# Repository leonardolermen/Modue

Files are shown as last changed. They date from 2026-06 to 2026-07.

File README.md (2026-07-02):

# Modue — Mixer Modular Magnético

Controlador físico modular para PC que controla individualmente o volume de aplicações (Discord, Spotify, Chrome, jogos…) através de módulos magnéticos, cada um com display touch e fader motorizado, comunicando via Bluetooth Low Energy.

> Inspirado em produtos como Monogram Creative Console e Intech Studio Grid, porém open-source, modular e a uma fração do custo.

## Arquitetura

Arquitetura do Modue

O firmware é um renderizador genérico **controlado pelo app de PC**: o módulo recebe comandos (volume, estado, cor, imagens) e devolve eventos de toque. Detalhes em [`docs/architecture.md`](docs/architecture.md) e o contrato em [`PROTOCOL.md`](PROTOCOL.md).

> 🛠️ **Rodar do zero numa máquina nova:** ver [`SETUP.md`](SETUP.md) (Arduino/libs, app Node, OpenSCAD, git).

## Hardware

- **MCU + Display:** ESP32-C6-Touch-LCD-1.47 (SpotPear/Waveshare) — display **JD9853** 172×320 + touch **AXS5106L**
- **Fader motorizado:** ALPS RS60N11M9A0
- **Driver de motor:** DRV8833 / TB6612FNG
- **Conexão entre módulos:** pogo pins magnéticos (energia) + BLE (dados)

## Pinagem (placa Touch — JD9853)

| Display | GPIO | | Touch | GPIO |
|---|---|---|---|---|
| SCK | 1 | | SDA | 18 |
| MOSI | 2 | | SCL | 19 |
| DC | 15 | | RST | 20 |
| CS | 14 | | INT | 21 |
| RST | 22 | | | |
| BL | 23 | | | |

**Fader físico** (potenciômetro 10kΩ, Donghong 119C 10KB — wiper no ADC1):

| Pino do fader | Liga em |
|---|---|
| 1 | 3.3V |
| 3 (wiper) | GPIO3 |
| 4 | GND |
| 2 | não usado |

> Motor (ponte-H) ainda não ligado. A leitura tem auto-calibração: deslize o curso completo uma vez após ligar.

> ⚠️ É a variante **Touch** (JD9853, não ST7789). O JD9853 precisa de sequência de init própria — ver `modue/`.

## Firmware (Arduino IDE)

| Sketch | Descrição |
|---|---|
| `modue/` | **Firmware principal** — renderizador dinâmico controlado pelo PC (LVGL) |
| `discordUI/` | UI do módulo em LVGL com tela Discord fixa (histórico) |
| `displayHello/` | Teste do display JD9853 + fader touch (Arduino_GFX) |

**Libs:** GFX Library for Arduino, LVGL 8.4, esp_lcd_touch_axs5106l
**Board:** ESP32C6 Dev Module · USB CDC On Boot: Enabled

## App de PC

Em `app/` (Node/Electron). Lê os eventos do módulo e aplica nos serviços (Discord, Spotify, volume). Veja [`app/README.md`](app/README.md) e o [`PROTOCOL.md`](PROTOCOL.md).

## Roadmap

- [x] Display JD9853 + touch AXS5106L
- [x] UI em LVGL (logo, fader, botões mute)
- [x] Ícones/logo reais no display
- [x] Protocolo bidirecional + firmware dinâmico (Fase A)
- [x] Envio de imagem pro display (Fase B)
- [x] Spotify — play/pause/skip + capa do álbum + volume (Web API)
- [x] Fader físico (potenciômetro via ADC, auto-calibrado)
- [ ] Shell do app Electron (Fase C)
- [ ] Discord RPC nativo + estado de volta (Fase D)
- [ ] Multi-módulo + perfis (Fase F)
- [ ] Fader motorizado (ponte-H) + BLE

Documentação completa em [`claude.md`](claude.md).

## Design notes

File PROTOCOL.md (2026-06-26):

# Protocolo Modue (PC ↔ módulo)

Comunicação por **USB serial** a **115200 baud**, linhas terminadas em `\n` (ASCII).
Bidirecional: o PC manda comandos, o módulo manda eventos.

## PC → Módulo (comandos)

| Comando | Efeito |
|---|---|
| `PING` | Módulo responde `PONG` (handshake/keepalive) |
| `SCREEN <discord\|spotify>` | Troca a tela/layout do módulo |
| `VOL <0-100>` | Move o fader pra essa posição (sem gerar evento de volta) |
| `STATE <mic\|deaf\|play> <0\|1>` | Define o estado de um botão (1 = ativo/mutado/tocando) |
| `LABEL <texto>` | Texto principal (nome da faixa na tela Spotify) |
| `COLOR <RRGGBB>` | Cor de destaque (fader e realces) |
| `IMG <slot> <w> <h>`<br>+ `w*h*2` bytes RGB565 | Envia imagem pro display (ex.: `IMG art 140 140` + bytes). Slot `art` = capa do álbum. RGB565 little-endian, opaco. |

## Módulo → PC (eventos)

| Evento | Quando |
|---|---|
| `HELLO modue <versao>` | No boot |
| `PONG` | Resposta ao `PING` |
| `EV VOL <0-100>` | Usuário moveu o fader |
| `EV BTN <mic\|deaf> <0\|1>` | Tela Discord: tocou no botão (estado novo) |
| `EV BTN play <0\|1>` | Tela Spotify: play/pause (1 = tocando) |
| `EV BTN <prev\|next> 1` | Tela Spotify: faixa anterior / próxima (momentâneo) |

## Regras

- Comandos/eventos desconhecidos são ignorados (compatibilidade pra frente).
- O PC é a fonte da verdade do estado: ao receber `EV BTN`, aplica no serviço
  (Discord etc.) e devolve `STATE` confirmando — assim o módulo reflete o estado real.
- `VOL`/`STATE` vindos do PC **não** geram `EV` de volta (evita eco/loop).

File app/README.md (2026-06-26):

# Modue PC bridge

Ponte entre o módulo físico e o PC: lê os eventos do fader/botões pela porta serial e aplica no Discord.

```
modulo (ESP32) --USB serial--> este app --> Discord (mute / deafen / volume)
```

Eventos que o firmware envia: `VOL <0-100>`, `MUTE_MIC on|off`, `MUTE_FONE on|off`.

## Instalar

```bash
cd pc
npm install
```

## Configurar o Discord (atalhos globais)

O app simula os **atalhos globais** do Discord. Configure em
**Discord → Configurações → Atalhos de Teclado** e adicione:

| Ação | Atalho (macOS) | Atalho (Windows) |
|---|---|---|
| Alternar mudo (mute) | `Ctrl+Alt+Cmd+M` | `Ctrl+Alt+Win+M` |
| Alternar surdo (deafen) | `Ctrl+Alt+Cmd+D` | `Ctrl+Alt+Win+D` |

> Os atalhos precisam bater com o `config.json` (`keybinds`). Pode trocar à vontade,
> só mantenha os dois lados iguais.

## Rodar

```bash
npm start
```

A porta serial é **auto-detectada** (`usbmodem` no Mac, `COM` no Windows). Para fixar,
edite `serialPort` no `config.json`.

> ⚠️ Feche o **Serial Monitor do Arduino** antes — a porta não pode ser aberta por dois programas.

## Notas por sistema

### macOS
- **Permissão necessária:** ao enviar o primeiro atalho, o macOS pede acesso de
  **Acessibilidade**. Vá em *Ajustes → Privacidade e Segurança → Acessibilidade* e
  habilite o **Terminal** (ou o app que rodou o `npm start`).
- **Volume:** o macOS não tem volume por-app nativo, então o fader controla o
  **volume de saída do sistema**. (Por-app exigiria um driver de áudio virtual.)

### Windows
- **Volume por-app:** usa o `svcl.exe` (NirSoft *SoundVolumeView*). Baixe em
  https://www.nirsoft.net/utils/sound_volume_view.html e coloque o `svcl.exe` na
  pasta `pc/` (ou ajuste `windows.svclPath` no `config.json`).
- O nome do processo do Discord está em `discordProcess` (`Discord.exe`).

## config.json

| Campo | Descrição |
|---|---|
| `serialPort` | `"auto"` ou caminho fixo (`/dev/cu.usbmodem1101`, `COM5`) |
| `baud` | 115200 (igual ao firmware) |
| `discordProcess` | nome do processo p/ volume no Windows |
| `keybinds.mute` / `.deafen` | combinação de teclas (precisa bater com o Discord) |
| `windows.svclPath` | caminho do `svcl.exe` |

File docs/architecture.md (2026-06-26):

# Arquitetura

Arquitetura do Modue

O firmware é um **renderizador genérico controlado pelo PC**. Em vez de telas fixas,
o módulo recebe comandos (volume, estado dos botões, cor, imagens) e devolve eventos
(toques no fader e nos botões). Quem decide o que cada módulo representa — Discord,
Spotify, etc. — é o app de PC.

## Camadas

- **Hardware (módulos):** ESP32-C6 + display touch JD9853. Cada módulo é um app.
  Desenha a UI em LVGL e emite eventos de toque.
- **App de PC (Electron):** núcleo do sistema.
  - *Gerenciador:* detecta módulos, guarda perfis e qual app está em cada um.
  - *Protocolo + imagens:* fala o [protocolo serial](../PROTOCOL.md) e envia logos/capas.
  - *Integrações:* conecta nos serviços e mantém o estado em tempo real.
- **Serviços externos:** Discord (RPC), Spotify (API) e o volume do sistema operacional.

## Comunicação

PC e módulo conversam por **USB serial, bidirecional** (futuramente BLE). O contrato
completo de comandos e eventos está em [`PROTOCOL.md`](../PROTOCOL.md).

## Fases de implementação

| Fase | Entrega | Status |
|---|---|---|
| A | Protocolo bidirecional + firmware dinâmico | ✅ |
| B | Envio de imagem pro display | ⏳ |
| C | Shell do app (Electron) | ⏳ |
| D | Discord RPC nativo (+ estado de volta) | ⏳ |
| E | Spotify (play/skip + capa) | ⏳ |
| F | Multi-módulo + perfis | ⏳ |

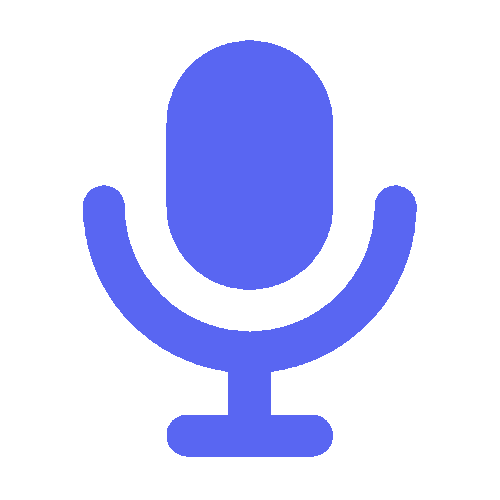
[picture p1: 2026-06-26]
assets/mic.png

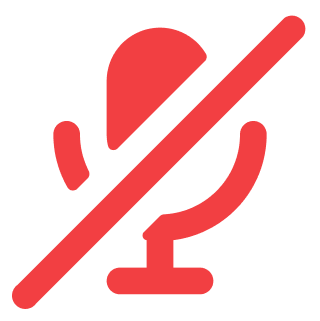
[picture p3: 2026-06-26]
assets/mic_muted.png

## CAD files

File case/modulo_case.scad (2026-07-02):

// ============================================================
//  Modue — Case do módulo (bandeja/corpo)  v1
//  Fader vertical + display no topo (em linha). Unidades: mm.
//
//  Origem: centro em X e Y; Z=0 = traseira (aberta, recebe a tampa);
//  frente (com janela do display + fenda do knob) em Z = out_d.
//  Componentes entram pela traseira.
// ============================================================

// ---------- Impressão / tolerâncias ----------
wall = 2.0;    // espessura de parede
fit  = 0.3;    // folga de encaixe (FDM)
$fn  = 40;

// ---------- Placa ESP32-C6-LCD-1.47 ----------
pcb_l = 36.37;
pcb_w = 20.32;
win_w = 17.7;   // janela do display (área visível)
win_h = 32.9;

// ---------- Fader (ALPS 80mm, travel 60) ----------
fad_l    = 80.0;
fad_w    = 18.0;
fad_up   = 8.2;    // acima da superfície de montagem
fad_deep = 17.8;   // abaixo (26 total − 8.2)
fad_trav = 60.0;   // curso do knob
slot_w   = 4.0;    // largura da fenda do knob

// ---------- Arranjo ----------
gap_fd = 4.0;   // vão fader <-> placa
usb_w  = 9.5;   // rasgo USB-C (largura)
usb_h  = 3.6;   // rasgo USB-C (altura)

// ---------- Derivadas ----------
inner_w = max(fad_w, pcb_w) + 2*fit;
inner_l = fad_l + gap_fd + pcb_l + 2*fit;
inner_d = fad_deep + fad_up + fit;    // profundidade útil (fader é o mais fundo)

out_w = inner_w + 2*wall;
out_l = inner_l + 2*wall;
out_d = inner_d + wall;               // parede da frente

// centros no comprimento (Y)
fad_y  = -inner_l/2 + fit + fad_l/2;
disp_y =  inner_l/2 - fit - pcb_l/2;

module box(w, l, d) { translate([-w/2,-l/2,0]) cube([w,l,d]); }

module tray() {
  difference() {
    // casca sólida
    box(out_w, out_l, out_d);

    // cavidade interna aberta na traseira (Z de -1 até out_d-wall)
    translate([0,0,-1]) box(inner_w, inner_l, (out_d - wall) + 1);

    // fenda do knob na frente (sobre o fader)
    translate([0, fad_y, out_d - wall - 1])
      box(slot_w, fad_trav, wall + 2);

    // janela do display na frente
    translate([0, disp_y, out_d - wall - 1])
      box(win_w, win_h, wall + 2);

    // rasgo do USB-C (parede lateral, perto da base/placa)
    translate([out_w/2 - wall - 1, disp_y, wall])
      box(wall + 2, usb_w, usb_h);
  }
}

tray();

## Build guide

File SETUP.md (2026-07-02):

# Setup do ambiente (máquina nova)

Guia pra colocar o projeto pra rodar do zero. Três frentes: **firmware** (Arduino),
**app de PC** (Node) e **case** (OpenSCAD).

---

## 1. Firmware (Arduino IDE)

### Board
- Instale o core **esp32** (Espressif) pelo Boards Manager — versão **≥ 3.0** (testado na 3.3.10).
- Selecione **ESP32C6 Dev Module**.
- Em *Tools*: **USB CDC On Boot: Enabled**, Flash Size **8MB**.

### Bibliotecas
| Lib | Como instalar | Versão |
|---|---|---|
| **GFX Library for Arduino** (moononournation) | Library Manager | 1.6.x |
| **LVGL** | ⚠️ **fixar na 8.4.0** — **NÃO** usar 9.x (API incompatível, quebra tudo) | 8.4.0 |
| **esp_lcd_touch_axs5106l** | copiar do demo da Waveshare (não está no Library Manager) | — |

O jeito mais garantido de ter a LVGL 8.4 + o driver de touch é pegar do **demo oficial**:

```
https://files.waveshare.com/wiki/ESP32-C6-Touch-LCD-1.47/ESP32-C6-Touch-LCD-1.47-Demo.zip
```

Dentro dele, copie `Arduino/libraries/lvgl` e `Arduino/libraries/esp_lcd_touch_axs5106l`
para a pasta de bibliotecas do Arduino (`~/Documents/Arduino/libraries/` no Mac,
`Documentos\Arduino\libraries\` no Windows).

> Se o Library Manager sugerir atualizar a LVGL pra 9.x, **ignore** — quebra a compilação.

### lv_conf.h (crítico)
Copie o `lv_conf.h` do exemplo do demo (`Arduino/examples/04_lvgl_arduino_v8/lv_conf.h`)
para a **raiz** da pasta de bibliotecas (`libraries/lv_conf.h`), e ajuste:

- `LV_COLOR_16_SWAP` → **0**  (senão as cores saem trocadas)
- `LV_TICK_CUSTOM` → **1**  (usa `millis()` do Arduino)
- Habilite as fontes: `LV_FONT_MONTSERRAT_20`, `_28`, `_40` → **1**

### Pinagem (já no código, mas pra referência)
Placa **ESP32-C6-Touch-LCD-1.47** (JD9853 + AXS5106L):
- Display (HW SPI): SCK=1, MOSI=2, DC=15, CS=14, RST=22, BL=23
- Touch (I²C): SDA=18, SCL=19, RST=20, INT=21
- Fader (pot 10k): wiper→GPIO3, extremos no 3V3/GND

Abra `modue/modue.ino` (as abas `board/screens/protocol/fader` aparecem sozinhas) e grave.

---

## 2. App de PC (Node)

```bash
cd app
npm install
```

- **Spotify:** o `config.json` já tem o `clientId` (público, ok no git). Registre o
  Redirect URI `http://127.0.0.1:8888/callback` no [Spotify Dashboard](https://developer.spotify.com/dashboard)
  se ainda não estiver. Os tokens (`.spotify-tokens.json`) **não** vão pro git — na
  primeira execução ele abre o navegador pra você autorizar de novo.
- Rodar o Spotify: `node src/spotify-run.js`
- **Windows:** pro volume por-app do Discord, baixe o `svcl.exe` (NirSoft) — ver `app/README.md`.

---

## 3. Case (OpenSCAD)

- Instale o **OpenSCAD** (https://openscad.org ou `brew install --cask openscad`).
- Abra `case/modulo_case.scad`. Variáveis de medida no topo do arquivo.

---

## 4. Git (empurrar de uma máquina nova)

Clone com a URL padrão (usa a chave SSH da conta pessoal da própria máquina):

```bash
git clone git@github.com:leonardolermen/Modue.git
```

> Obs: no Mac de trabalho foi usado um alias `github-personal` no `~/.ssh/config`
> porque a chave padrão dali era da conta do trabalho. Numa máquina pessoal onde a
> conta do GitHub já é a `leonardolermen`, não precisa de alias — a URL padrão funciona.
> (Ou use HTTPS + token.)

---

## Estrutura do repo

| Pasta | O que é |
|---|---|
| `modue/` | firmware (abas .ino) — firmware principal |
| `app/` | app de PC (Node): serial + Spotify + imagens |
| `case/` | modelo 3D do case (OpenSCAD) |
| `docs/` | arquitetura + diagrama |
| `discordUI/`, `displayHello/` | sketches antigos (histórico) |
| `PROTOCOL.md` | contrato serial PC↔módulo |

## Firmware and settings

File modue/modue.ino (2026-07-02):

// ============================================================
//  Mixer Modular Magnético — Firmware dinâmico (controlado pelo PC)
//  Placa: SpotPear/Waveshare ESP32-C6-Touch-LCD-1.47 (JD9853 + AXS5106L)
//
//  Renderizador genérico com telas trocáveis (Discord / Spotify).
//  PC manda comandos (SCREEN/VOL/STATE/COLOR/LABEL/IMG); módulo devolve
//  eventos (EV VOL / EV BTN). Ver PROTOCOL.md.
//
//  Organização (abas .ino, concatenadas pelo Arduino):
//    modue.ino    -> includes, config, globais, setup(), loop()
//    board.ino    -> init JD9853 + glue do LVGL/touch
//    screens.ino  -> telas Discord/Spotify + callbacks de toque
//    protocol.ino -> serial: comandos do PC e recepção de imagem
//    fader.ino    -> leitura do fader físico (ADC) + calibração
//
//  Libs: GFX Library for Arduino, lvgl 8.4, esp_lcd_touch_axs5106l
//  Board: ESP32C6 Dev Module | USB CDC On Boot: Enabled
// ============================================================

#include <lvgl.h>
#include <Arduino_GFX_Library.h>
#include <Wire.h>
#include "esp_lcd_touch_axs5106l.h"
#include "icons.h"  // img_discord, img_mic, img_mic_muted (defaults)

#define FW_VERSION "0.3.0"

// ---- Display JD9853 ----
#define GFX_BL 23
Arduino_DataBus *bus = new Arduino_HWSPI(15, 14, 1, 2);
Arduino_GFX *gfx = new Arduino_ST7789(bus, 22, 0, false, 172, 320, 34, 0, 34, 0);

// ---- Touch AXS5106L ----
#define TP_SDA 18
#define TP_SCL 19
#define TP_RST 20
#define TP_INT 21

// ---- Fader fisico (potenciometro do ALPS, via ADC) ----
#define FADER_ENABLED 1   // 0 = desliga (use 0 enquanto NAO ligou o fader no GPIO3)
#define FADER_DEBUG   0   // 1 = imprime o valor cru do ADC no serial (debug)
#define FADER_PIN 3       // wiper do potenciometro -> ADC1_CH3

// ---- Cores ----
#define C_BG       0x0a0b10
#define C_TRACK    0x1c1f29
#define C_BTN      0x15171f
#define C_BTN_MUTE 0x2b1417
#define C_RED      0xe24b4a
#define C_LIGHT    0xcfd2da

// ---- Capa do album (recebida via comando IMG) ----
#define MAX_ART 40000  // 140*140*2 = 39200

// Tipos no topo (o Arduino gera protótipos antes das funções nas outras abas)
enum Screen { SCR_DISCORD, SCR_SPOTIFY };

// ============================================================
//  Globais (definidos aqui; visíveis em todas as abas .ino — é uma TU só)
//  static = linkagem interna, evita colisão de nome com as libs.
// ============================================================
static uint32_t accent = 0x5865F2;

// LVGL glue
static lv_disp_draw_buf_t draw_buf;
static lv_color_t *buf1;
static lv_disp_drv_t disp_drv;

// Estado
static Screen current = SCR_DISCORD;
static bool suppressEv = false;

// Widgets
static lv_obj_t *slider, *volLabel;                                   // comuns
static lv_obj_t *micBtn, *micImg, *foneBtn, *foneLbl;                 // discord
static lv_obj_t *trackLabel, *prevBtn, *playBtn, *playLbl, *nextBtn, *artImg;  // spotify

// Recepcao de imagem (nao-bloqueante)
static uint8_t *artBuf = NULL;
static lv_img_dsc_t artDsc;
static int imgW = 0, imgH = 0;
static size_t imgRemaining = 0, imgPos = 0;
static uint32_t imgLast = 0;

// Parser de comandos
static char lineBuf[160];
static uint8_t lineLen = 0;

// ============================================================
void setup() {
  Serial.setRxBufferSize(MAX_ART + 2048);  // segura o jorro da imagem sem perder bytes
  Serial.begin(115200);
  delay(300);

#if FADER_ENABLED
  // ADC: por padrao o ESP32 satura em ~1.1V. Com 12dB le o range ~0..3.3V.
  analogReadResolution(12);
  analogSetPinAttenuation(FADER_PIN, ADC_11db);
#endif

  if (!gfx->begin()) Serial.println("gfx->begin() FALHOU");
  lcd_reg_init();
  gfx->setRotation(0);
  gfx->fillScreen(RGB565_BLACK);
  pinMode(GFX_BL, OUTPUT);
  digitalWrite(GFX_BL, HIGH);

  Wire.begin(TP_SDA, TP_SCL);
  bsp_touch_init(&Wire, TP_RST, TP_INT, gfx->getRotation(), gfx->width(), gfx->height());

  lv_init();
  uint32_t bufSize = 172 * 40;
  buf1 = (lv_color_t *)heap_caps_malloc(bufSize * 2, MALLOC_CAP_INTERNAL | MALLOC_CAP_8BIT);
  if (!buf1) buf1 = (lv_color_t *)malloc(bufSize * 2);
  lv_disp_draw_buf_init(&draw_buf, buf1, NULL, bufSize);

  lv_disp_drv_init(&disp_drv);
  disp_drv.hor_res = 172;
  disp_drv.ver_res = 320;
  disp_drv.flush_cb = my_disp_flush;
  disp_drv.draw_buf = &draw_buf;
  lv_disp_drv_register(&disp_drv);

  static lv_indev_drv_t indev_drv;
  lv_indev_drv_init(&indev_drv);
  indev_drv.type = LV_INDEV_TYPE_POINTER;
  indev_drv.read_cb = touchpad_read_cb;
  lv_indev_drv_register(&indev_drv);

  switch_screen(SCR_DISCORD);
  txln("HELLO modue " FW_VERSION);
}

void loop() {
  pollSerial();
  // Enquanto recebe a imagem, drena rapido (sem desenhar) pra nao perder bytes.
  if (imgRemaining > 0) return;
#if FADER_ENABLED
  readFader();
#endif
  lv_timer_handler();
  delay(5);
}

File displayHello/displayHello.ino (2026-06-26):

// ============================================================
//  Mixer Modular Magnético — Teste 04: Fader TOUCH
//  Placa: SpotPear/Waveshare ESP32-C6-Touch-LCD-1.47
//  Display JD9853 172x320  |  Touch AXS5106L (I2C addr 0x63)
//
//  Arraste o dedo pra cima/baixo na barra: o volume acompanha.
//  Pinos display: SCK=1 MOSI=2 DC=15 CS=14 RST=22 BL=23
//  Pinos touch  : SDA=18 SCL=19 RST=20 INT=21
//
//  Lib: "GFX Library for Arduino" (Moon On Our Nation)
//  Board: ESP32C6 Dev Module | USB CDC On Boot: Enabled
// ============================================================

#include <Arduino_GFX_Library.h>
#include <Wire.h>

#define GFX_BL 23

// ---- Touch AXS5106L ----
#define TP_SDA 18
#define TP_SCL 19
#define TP_RST 20
#define TP_INT 21
#define TP_ADDR 0x63
#define TP_DATA_REG 0x01

Arduino_DataBus *bus = new Arduino_HWSPI(15 /* DC */, 14 /* CS */, 1 /* SCK */, 2 /* MOSI */);
Arduino_GFX *gfx = new Arduino_ST7789(
    bus, 22 /* RST */, 0 /* rotation */, false /* IPS */,
    172, 320, 34, 0, 34, 0);

// Para paisagem: troque o rotation acima pra 1 ou 3 e ajuste o layout.

// ---- Init proprio do JD9853 (demo oficial Waveshare) ----
void lcd_reg_init(void) {
  static const uint8_t op[] = {
    BEGIN_WRITE, WRITE_COMMAND_8, 0x11, END_WRITE, DELAY, 120,
    BEGIN_WRITE,
    WRITE_C8_D16, 0xDF, 0x98, 0x53,
    WRITE_C8_D8, 0xB2, 0x23,
    WRITE_COMMAND_8, 0xB7, WRITE_BYTES, 4, 0x00, 0x47, 0x00, 0x6F,
    WRITE_COMMAND_8, 0xBB, WRITE_BYTES, 6, 0x1C, 0x1A, 0x55, 0x73, 0x63, 0xF0,
    WRITE_C8_D16, 0xC0, 0x44, 0xA4,
    WRITE_C8_D8, 0xC1, 0x16,
    WRITE_COMMAND_8, 0xC3, WRITE_BYTES, 8, 0x7D, 0x07, 0x14, 0x06, 0xCF, 0x71, 0x72, 0x77,
    WRITE_COMMAND_8, 0xC4, WRITE_BYTES, 12, 0x00, 0x00, 0xA0, 0x79, 0x0B, 0x0A, 0x16, 0x79, 0x0B, 0x0A, 0x16, 0x82,
    WRITE_COMMAND_8, 0xC8, WRITE_BYTES, 32,
      0x3F, 0x32, 0x29, 0x29, 0x27, 0x2B, 0x27, 0x28, 0x28, 0x26, 0x25, 0x17, 0x12, 0x0D, 0x04, 0x00,
      0x3F, 0x32, 0x29, 0x29, 0x27, 0x2B, 0x27, 0x28, 0x28, 0x26, 0x25, 0x17, 0x12, 0x0D, 0x04, 0x00,
    WRITE_COMMAND_8, 0xD0, WRITE_BYTES, 5, 0x04, 0x06, 0x6B, 0x0F, 0x00,
    WRITE_C8_D16, 0xD7, 0x00, 0x30,
    WRITE_C8_D8, 0xE6, 0x14,
    WRITE_C8_D8, 0xDE, 0x01,
    WRITE_COMMAND_8, 0xB7, WRITE_BYTES, 5, 0x03, 0x13, 0xEF, 0x35, 0x35,
    WRITE_COMMAND_8, 0xC1, WRITE_BYTES, 3, 0x14, 0x15, 0xC0,
    WRITE_C8_D16, 0xC2, 0x06, 0x3A,
    WRITE_C8_D16, 0xC4, 0x72, 0x12,
    WRITE_C8_D8, 0xBE, 0x00,
    WRITE_C8_D8, 0xDE, 0x02,
    WRITE_COMMAND_8, 0xE5, WRITE_BYTES, 3, 0x00, 0x02, 0x00,
    WRITE_COMMAND_8, 0xE5, WRITE_BYTES, 3, 0x01, 0x02, 0x00,
    WRITE_C8_D8, 0xDE, 0x00,
    WRITE_C8_D8, 0x35, 0x00,
    WRITE_C8_D8, 0x3A, 0x05,
    WRITE_COMMAND_8, 0x2A, WRITE_BYTES, 4, 0x00, 0x22, 0x00, 0xCD,
    WRITE_COMMAND_8, 0x2B, WRITE_BYTES, 4, 0x00, 0x00, 0x01, 0x3F,
    WRITE_C8_D8, 0xDE, 0x02,
    WRITE_COMMAND_8, 0xE5, WRITE_BYTES, 3, 0x00, 0x02, 0x00,
    WRITE_C8_D8, 0xDE, 0x00,
    WRITE_C8_D8, 0x36, 0x00,
    WRITE_COMMAND_8, 0x21,
    END_WRITE, DELAY, 10,
    BEGIN_WRITE, WRITE_COMMAND_8, 0x29, END_WRITE
  };
  bus->batchOperation(op, sizeof(op));
}

// ---- Leitura do touch (polling, sem interrupcao) ----
// Retorna true se ha dedo na tela; preenche tx,ty em coords de tela.
bool lerTouch(int &tx, int &ty) {
  uint8_t d[14];
  Wire.beginTransmission(TP_ADDR);
  Wire.write(TP_DATA_REG);
  if (Wire.endTransmission() != 0) return false;
  if (Wire.requestFrom(TP_ADDR, (uint8_t)14) != 14) return false;
  for (int i = 0; i < 14; i++) d[i] = Wire.read();

  uint8_t n = d[1];               // numero de toques
  if (n == 0) return false;

  uint16_t rawX = ((uint16_t)(d[2] & 0x0F) << 8) | d[3];
  uint16_t rawY = ((uint16_t)(d[4] & 0x0F) << 8) | d[5];
  // rotation 0: x espelhado, y direto
  tx = 171 - rawX;
  ty = rawY;
  return true;
}

void resetTouch() {
  pinMode(TP_RST, OUTPUT);
  digitalWrite(TP_RST, LOW);  delay(200);
  digitalWrite(TP_RST, HIGH); delay(300);
  pinMode(TP_INT, INPUT_PULLUP);
}

// ---- Layout do fader ----
const int TRK_X = 46, TRK_W = 80;     // trilha
const int TRK_Y = 70, TRK_H = 200;    // topo e altura
#define COR_BARRA  0x07E0   // verde
#define COR_TRILHA 0x2104   // cinza bem escuro
#define COR_KNOB   0xFFFF   // branco

int volume = 50;
int volAnterior = -1;

void desenhaFader(int v) {
  // trilha
  gfx->fillRoundRect(TRK_X, TRK_Y, TRK_W, TRK_H, 10, COR_TRILHA);
  // preenchimento de baixo pra cima
  int fill = (TRK_H * v) / 100;
  gfx->fillRoundRect(TRK_X, TRK_Y + (TRK_H - fill), TRK_W, fill, 10, COR_BARRA);
  // "knob" (linha do nivel)
  int ky = TRK_Y + (TRK_H - fill);
  gfx->fillRoundRect(TRK_X - 6, ky - 4, TRK_W + 12, 8, 4, COR_KNOB);

  // numero
  gfx->fillRect(0, TRK_Y + TRK_H + 14, 172, 40, RGB565_BLACK);
  gfx->setTextColor(RGB565_WHITE);
  gfx->setTextSize(4);
  char buf[8];
  snprintf(buf, sizeof(buf), "%d", v);
  int16_t x1, y1; uint16_t w, h;
  gfx->getTextBounds(buf, 0, 0, &x1, &y1, &w, &h);
  gfx->setCursor((172 - w) / 2, TRK_Y + TRK_H + 18);
  gfx->print(buf);
}

void setup() {
  Serial.begin(115200);
  delay(300);
  Serial.println("\n[Modue] Teste 04 - Fader Touch");

  // Display
  if (!gfx->begin()) Serial.println("gfx->begin() FALHOU");
  lcd_reg_init();
  gfx->setRotation(0);
  gfx->fillScreen(RGB565_BLACK);
  pinMode(GFX_BL, OUTPUT);
  digitalWrite(GFX_BL, HIGH);

  // Touch
  Wire.begin(TP_SDA, TP_SCL);
  resetTouch();

  // Titulo
  gfx->setTextColor(0x07FF);
  gfx->setTextSize(3);
  gfx->setCursor(20, 20);
  gfx->print("Discord");

  Serial.println("Pronto. Arraste o dedo na barra.");
}

void loop() {
  int tx, ty;
  if (lerTouch(tx, ty)) {
    // se o toque esta na faixa vertical do fader, define o volume
    if (ty >= TRK_Y - 10 && ty <= TRK_Y + TRK_H + 10) {
      int v = (int)((float)(TRK_Y + TRK_H - ty) / TRK_H * 100.0f + 0.5f);
      volume = constrain(v, 0, 100);
    }
  }

  if (volume != volAnterior) {
    desenhaFader(volume);
    volAnterior = volume;
    Serial.printf("Volume: %d%%\n", volume);
  }
  delay(15);
}

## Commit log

2026-06-26 Initial commit: firmware Modue (display JD9853 + UI Discord LVGL)
    - displayHello: teste display JD9853 + fader touch (Arduino_GFX)
    - discordUI: UI do modulo em LVGL (logo, fader horizontal, botoes mute mic/fone)
    - claude.md/README: pinagem real da placa Touch (JD9853 + AXS5106L)
2026-06-26 Fase A: firmware dinamico + protocolo + app PC + docs
    - modue/: firmware principal controlado pelo PC (parser de comandos
    VOL/STATE/COLOR/PING, emite eventos EV VOL/EV BTN, bidirecional)
    - PROTOCOL.md: contrato serial PC<->modulo
    - app/: bridge Node cross-platform (serial + Discord via atalhos) + testador da fundacao
    - discordUI/: logo + icones reais embutidos (icons.h) + fix de performance (throttle serial)
    - docs/: diagrama de arquitetura (SVG) + pagina de arquitetura, embutidos no README
    [modue.ino]
2026-06-27 Spotify real (Web API) + capa no display + fader fisico
    - Firmware: tela Spotify (capa + faixa + transporte), comando IMG (recebe
    capa RGB565 sem bloquear), leitura do fader fisico via ADC com auto-calibracao
    - app/: integracao Spotify Web API (OAuth PKCE), envio de capa (jimp->RGB565),
    runner que espelha estado e aplica controles
    - PROTOCOL: SCREEN/LABEL/IMG + eventos de transporte
    - docs/README: roadmap atualizado, pinagem do fader
2026-06-27 Fader fisico: leitura calibrada (mV) + curva de linearizacao
    - analogReadMilliVolts (ADC calibrado) no lugar do raw
    - tabela de calibracao por interpolacao (lineariza o taper do fader)
    - debug desligado
    - README: pinagem do fader (1=3V3, 3=wiper/GPIO3, 4=GND)
2026-07-02 Case v1 (OpenSCAD): bandeja parametrica do modulo
    - fader vertical 80mm + display no topo (em linha)
    - bolso do fader, fenda do knob (60mm), janela do display, rasgo USB-C
    - medidas da placa (36.37x20.32) e do fader do datasheet
    - tampa/knob/postes/imas: proximos passos (iterar com render)
    [modulo_case.scad]
2026-07-02 Refatora firmware em abas (.ino)
    Quebra o modue.ino (~526 linhas) em:
    - modue.ino: includes, config, globais, setup/loop
    - board.ino: init JD9853 + glue LVGL/touch
    - screens.ino: telas Discord/Spotify + callbacks
    - protocol.ino: serial (comandos + recepcao de imagem)
    - fader.ino: leitura do fader + calibracao
    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
2026-07-02 Docs: SETUP.md (setup do ambiente numa maquina nova) + gitignore de render do case
    - guia de firmware (Arduino/LVGL 8.4/lv_conf), app Node, OpenSCAD e git
    - link no README
    - ignora case/*.png,*.stl,*.3mf
